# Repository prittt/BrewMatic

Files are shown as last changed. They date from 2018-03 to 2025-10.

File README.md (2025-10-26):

# BrewMatic - Automated Brewing System



<p align="center">
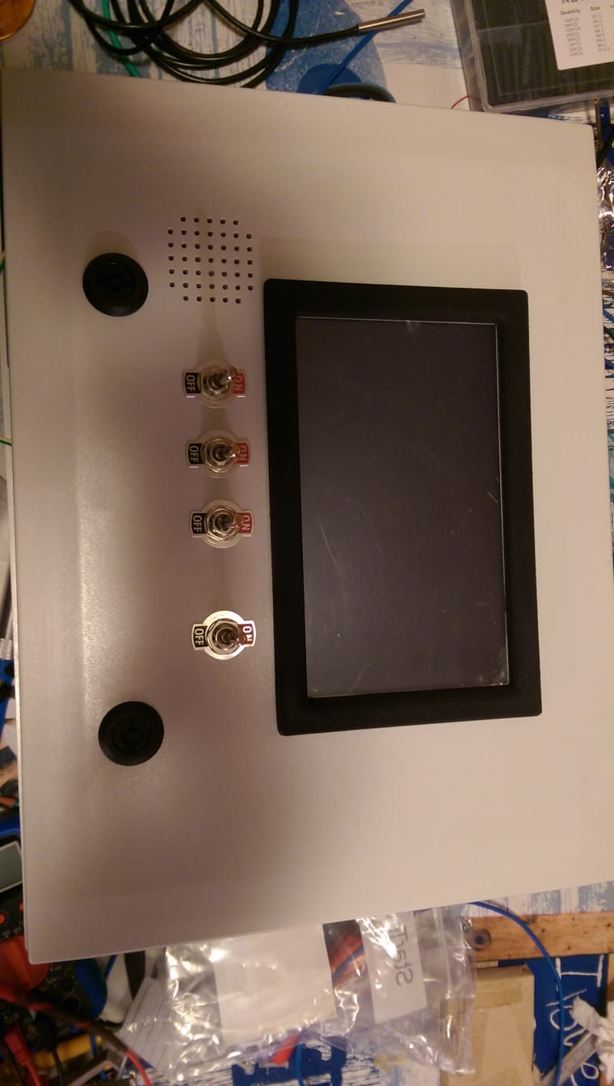
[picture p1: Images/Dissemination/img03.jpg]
  
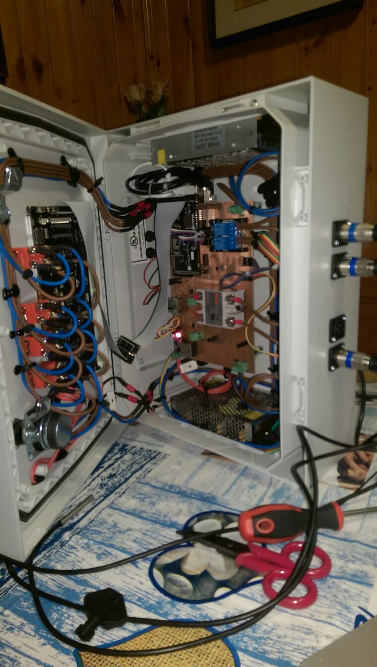
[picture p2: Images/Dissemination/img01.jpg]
  
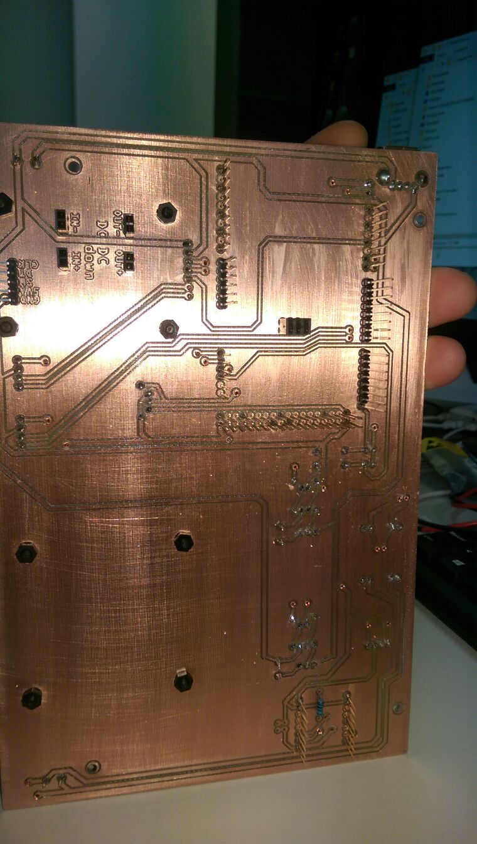
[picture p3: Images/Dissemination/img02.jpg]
  
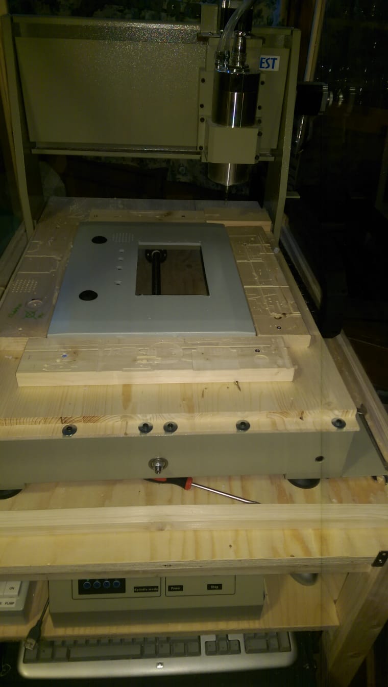
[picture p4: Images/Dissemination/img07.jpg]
  
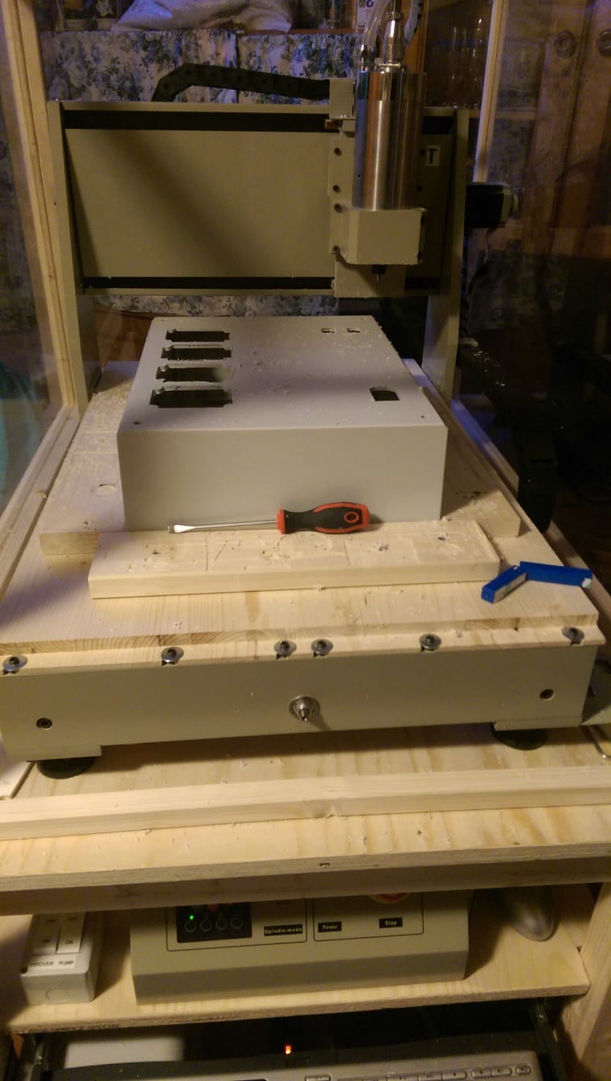
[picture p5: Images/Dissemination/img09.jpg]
  
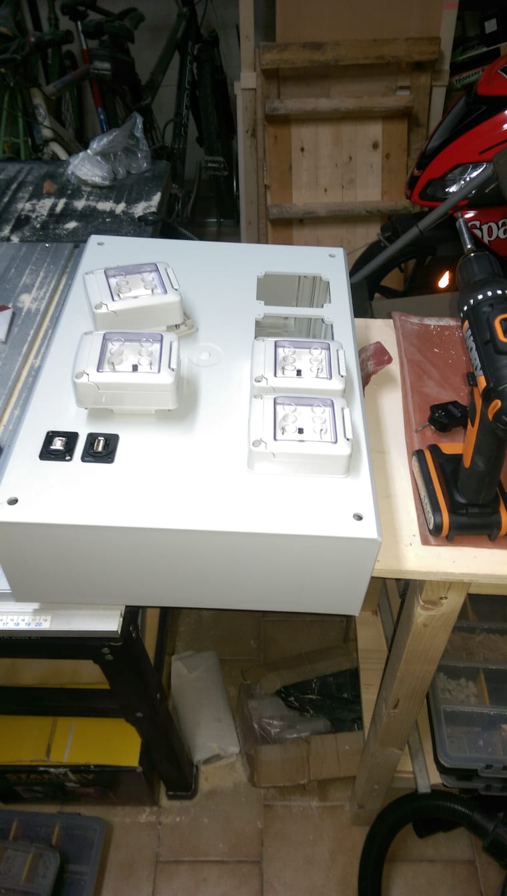
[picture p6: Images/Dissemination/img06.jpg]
  
</p>

<p align="center">
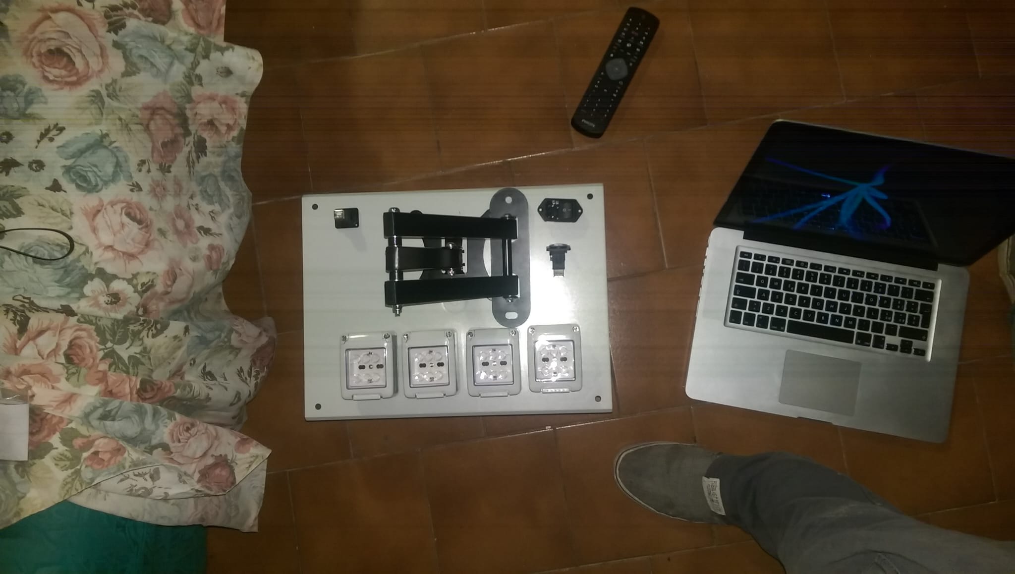
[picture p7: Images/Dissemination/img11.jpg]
  
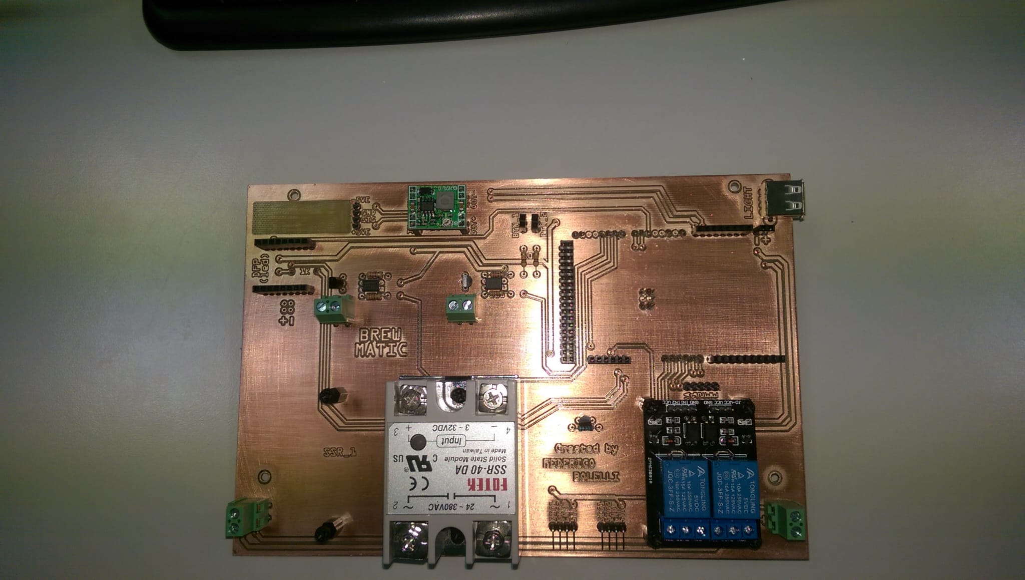
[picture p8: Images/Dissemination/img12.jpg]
  
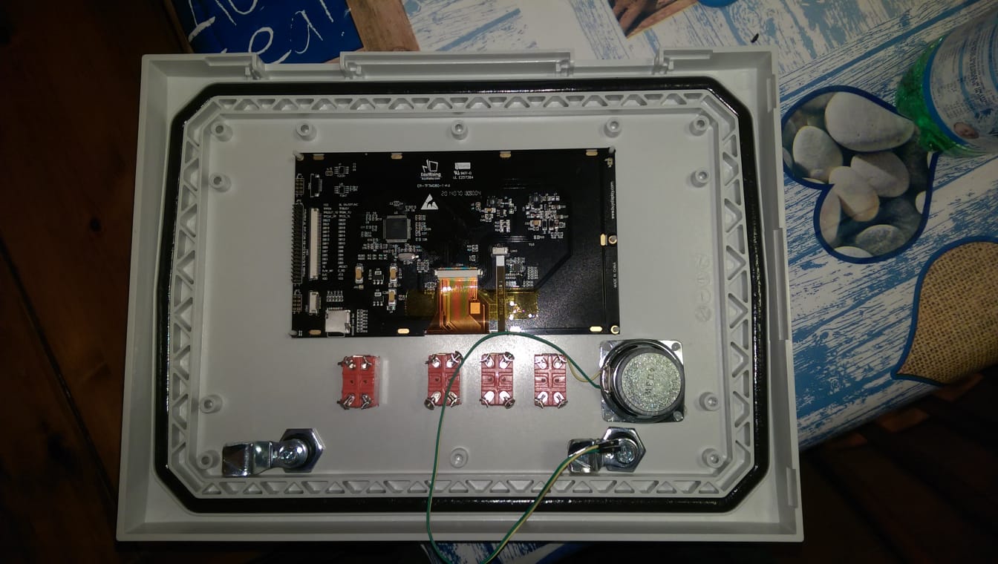
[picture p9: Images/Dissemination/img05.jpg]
  
</p>

An Arduino-based automated brewing control system with touch screen interface for managing mash, sparge, and boil processes.

## Overview

BrewMatic is a comprehensive brewing automation system built on Arduino Mega 2560 with a large TFT touch display (800x480). The system provides automated temperature control, step management, and real-time monitoring for the entire brewing process.

### Key Features

- **Multi-stage Process Control**: Automated management of Mash, Sparge, and Boil phases
- **Temperature Monitoring**: Multiple DS18B20 sensors for precise temperature control
- **Touch Screen Interface**: Intuitive GUI with tabs, buttons, and real-time data visualization
- **Recipe Management**: Configurable brewing recipes with multiple mash steps
- **Safety Features**: Temperature delta monitoring, sensor error detection, hysteresis control
- **Fire Control**: SSR-based heating element control with safety interlocks
- **Audio Feedback**: Buzzer alerts for process transitions

## Hardware Requirements

### Main Components
- **Microcontroller**: Arduino Mega 2560
- **Display**: 800x480 TFT LCD (SSD1963 controller) with resistive touch
- **Temperature Sensors**: DS18B20 (OneWire) sensors for:
  - Mash (upper and lower)
  - Sparge
  - Environment/backup
- **Relays/SSRs**: Solid State Relays for heating element control
- **Audio**: Buzzer for notifications

### Pin Connections
See `mega_pins.h` for detailed pin assignments:
- Temperature sensors on various digital pins
- SSR control pins
- Display connection (38, 39, 40, 41)
- Touch screen interface

## Software Architecture

### Project Versions

The workspace contains three main versions:

1. **BrewMatic**: Original implementation
2. **BrewMaticAlpha01**: First alpha release
3. **BrewMaticAlpha02**: Latest alpha version (recommended)

### Core Libraries Used

- **AWind**: Window/GUI framework for Arduino
- **ASensor**: Sensor management framework
- **AFrame**: Arduino framework for sensor integration
- **UTFT**: TFT display driver
- **UTouch**: Touch screen driver
- **OneWire**: Temperature sensor communication

### Main Components

#### View Layer
- `MenuWindow.h`: Main navigation menu
- `BrewWindow.h`: Tab control for brew processes
- `Mash.h`: Mash process window and controller
- `Sparge.h`: Sparge process window and controller
- `RecipeWindow.h`: Recipe configuration interface
- `SettingsWindow.h`: System settings

#### Controller Layer
- `Recipe.h`: Recipe data structures and configuration
- `PlantParams.h`: Plant-specific parameters
- `utilities.h`: Helper functions and utilities

#### Model Layer
- `SensorManager`: Centralized sensor management
- `DS18B20Sensor`: Temperature sensor wrapper

## Installation

### Library Setup

#### Option 1: Using install_libs.sh (Mac/Linux)

```bash
./install_libs.sh
```

This script creates symbolic links from the project's `libs` folder to your Arduino libraries folder.

#### Option 2: Manual Installation

1. Copy the following libraries to your Arduino libraries folder:
   - `BrewMaticAlpha02/libs/AFrame` → `libraries/BrewMaticAlpha02AFrame`
   - `BrewMaticAlpha02/libs/ASensor` → `libraries/BrewMaticAlpha02ASensor`
   - `BrewMaticAlpha02/libs/AWind` → `libraries/BrewMaticAlpha02AWind`
   - `BrewMaticAlpha02/libs/UTFT` → `libraries/BrewMaticAlpha02UTFT`
   - `BrewMaticAlpha02/libs/UTouch` → `libraries/BrewMaticAlpha02UTouch`

2. Install additional required libraries:
   - OneWire (for DS18B20 sensors)
   - Arduino Timer libraries

### Hardware Setup

1. Connect the TFT display according to UTFT library specifications
2. Wire DS18B20 temperature sensors with 4.7kΩ pull-up resistors
3. Connect SSRs to the designated control pins
4. Wire buzzer for audio feedback
5. Ensure proper power supply for all components

### Configuration

#### Recipe Configuration

Edit `Recipe.h` to configure your brewing recipe:

```cpp
mashStep mashSteps[] = {
    {50, 10, 1, false, 0},  // 50°C for 10 minutes
    {62, 30, 1, false, 0},  // 62°C for 30 minutes
    {72, 20, 1, false, 0},  // 72°C for 20 minutes
    {78, 5,  1, false, 0}   // 78°C for 5 minutes (mash out)
};
```

#### Plant Parameters

Adjust `PlantParams.h` for your specific setup:

```cpp
#define MAX_DELTA 3.0        // Maximum allowed temperature delta
#define HYSTERESIS 0.5       // Temperature control hysteresis
#define INERTIA 2.0          // System thermal inertia
```

## Usage

### Starting a Brew Session

1. **Power On**: The system initializes and displays the main menu
2. **Recipe Selection**: Navigate to the recipe window to select/configure recipe
3. **Sensor Calibration**: Verify all temperature sensors are reading correctly
4. **Start Mash**: 
   - Navigate to Mash tab
   - Press "Start Mash" button
   - Add grains when target mash-in temperature is reached

### Mash Process

The `Mash` class manages multi-step mashing:

- **Temperature Ramp**: Automatically heats to target temperature
- **Rest Period**: Maintains temperature for specified duration
- **Step Progress**: Visual indication of current step and time remaining
- **Iodine Test**: Optional extended rest periods with user control
- **Mash Out**: Final step with buzzer notification

Key features:
- Real-time temperature display (upper, lower, average)
- Fire status indicator
- Step progress visualization
- Manual step duration adjustment

### Sparge Process

The `Sparge` class manages sparge water heating:

- Target temperature: 78°C (configurable)
- Automatic fire control
- Temperature monitoring
- Completion notification

### Safety Features

1. **Temperature Delta Check**: 
   - Monitors difference between upper and lower mash sensors
   - Automatically disables heating if delta exceeds threshold
   - Prevents scorching and uneven heating

2. **Sensor Error Detection**:
   - Validates sensor readings
   - Disables heating on sensor failures
   - Visual and audio warnings

3. **Hysteresis Control**:
   - Prevents rapid on/off cycling
   - Extends equipment lifespan

## Development

### Project Structure

```
BrewMaticAlpha02/
├── BrewMaticAlpha02.ino    # Main Arduino sketch
├── libs/                    # Core libraries
│   ├── AFrame/             # Arduino framework
│   ├── ASensor/            # Sensor management
│   ├── AWind/              # GUI framework
│   ├── UTFT/               # Display driver
│   └── UTouch/             # Touch driver
├── Mash.h                  # Mash process (View + Controller)
├── Sparge.h                # Sparge process
├── MenuWindow.h            # Main menu
├── BrewWindow.h            # Tab control
├── Recipe.h                # Recipe configuration
├── PlantParams.h           # System parameters
└── utilities.h             # Helper functions
```

### Key Classes

#### Mash Class
Location: `Mash.h`

Implements both View and Controller for the mash process:

```cpp
class Mash : public Window, 
             public ISensorHasDataEventReceiver, 
             public ISensorMeasuredEventReceiver, 
             public ITouchEventReceiver
{
    // View components
    TextBoxString *mash_up_temp_str_;
    TextBoxString *mash_down_temp_str_;
    TextBoxString *mash_avg_temp_str_;
    ImageWindow *flames_img_;
    
    // Controller methods
    void HandleStep();
    void CheckTemperatures();
    void SetFire();
    void UpdateScreenStepData();
};
```

#### SensorManager
Location: `libs/AFrame/SensorManager.h`

Manages sensor measurements and event notifications:

```cpp
SensorManager *mash_up_temp_manager = new SensorManager(
    mash_up_temp, -10, 110, 1000*10, false, F("MASH_UP")
);
```

### Adding New Features

1. **New Sensor**: Create sensor in `setup()`, register with `SensorManager`
2. **New Window**: Inherit from `Window`, implement `ISensorHasDataEventReceiver`
3. **New Recipe Step**: Modify `mashStep` structure in `Recipe.h`

## Examples

The `Arduino Project Examples` folder contains isolated examples:

- **all_together**: Combined hardware test
- **buttons**: Button handling examples
- **Music_Player**: DFPlayer integration
- **TemperatureSensor**: DS18B20 sensor examples
- **ScreenDrawingTest**: Display graphics tests
- **SD_on_LCD_screen**: SD card bitmap display

## Hardware Enclosure

The `Case` folder contains:
- Front panel design
- Back panel design
- Frame specifications
- CNC machining instructions

## PCB Designs

The `PCBs` folder contains circuit board designs for:
- Temperature sensor connections
- Power distribution
- Control interfaces

## License

This project uses multiple open-source libraries with different licenses:

- **AWind Library**: Apache License 2.0
- **BrewMatic Code**: BSD 3-Clause License (see file headers)
- **UTFT Library**: CC BY-NC-SA 3.0

Copyright (c) 2018 Federico Bolelli

## Contributing

When contributing to this project:

1. Follow the existing code style
2. Test thoroughly with actual hardware
3. Update documentation for new features
4. Add examples for complex functionality

## Troubleshooting

### Display Issues
- Verify pin connections match `BrewMaticAlpha02.ino` setup
- Check backlight pin (pin 8) is HIGH
- Ensure UTFT library is correctly installed

### Sensor Problems
- Verify 4.7kΩ pull-up resistor on OneWire bus
- Check sensor addresses using OneWire scanner
- Monitor Serial output for sensor readings

### Touch Not Responding
- Run touch calibration
- Update calibration values in `UTouchCD.h`
- Check precision setting: `myTouch.setPrecision(PREC_MEDIUM)`

### Memory Issues
- Arduino Mega has limited SRAM
- Use `F()` macro for string literals
- Monitor free RAM: `AHelper::LogFreeRam()`

## Useful Links

- Link Utili PID-SSR: See `Link Utili PID-SSR.txt`
- Link Utili Speaker: See `Link Utili Speaker.txt`

---

**Note**: This is an active development project. Always refer to the latest code in `BrewMaticAlpha02` for the most current implementation.

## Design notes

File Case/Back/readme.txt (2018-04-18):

single height step: 2mm candle cutter
time: few minutes
vertical zero: upper surface - plastic thickness

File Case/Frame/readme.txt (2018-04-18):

roughing: 3mm spherical cutter
finishing: 3mm spherical cutter
time: more than 4 hours
material: wooden
material thickness: 6mm
vertical zero: lower face of the material

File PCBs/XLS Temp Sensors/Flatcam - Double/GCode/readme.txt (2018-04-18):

traces: 0.5mm candle or better V-cutter like http://pcbfacile.com/frese-v-groove-a-spirale/151--fresa-per-scoring-30-in-carburo-di-tungsteno-flat-version-802.html
holes: 0.8mm candle cutter (better if it is for alluminium like http://pcbfacile.com/frese-per-alluminio/2387-frese-2-taglienti-in-carburo-solido-per-alluminio-08mm-.html)
board cutout: 3mm candle cutter
time: few minutes
vertical zero: PCB upper surface

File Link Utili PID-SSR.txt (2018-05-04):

PID: 

Arduino Library:
https://playground.arduino.cc/Code/PIDLibraryConstructor

Additional Theoretical Information
http://brettbeauregard.com/blog/2017/06/introducing-proportional-on-measurement/

Forums (Similar Issue): 
http://forum.arduino.cc/index.php?topic=5678.0
http://forum.arduino.cc/index.php?topic=155720.0

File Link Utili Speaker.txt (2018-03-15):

https://www.arduino.cc/en/Tutorial/SimpleAudioPlayer

https://maker.pro/projects/arduino/arduino-audio-player

Robot Italy
product: https://www.robot-italy.com/it/dfplayer-a-mini-mp3-player-for-arduino.html
links:  
	https://www.dfrobot.com/wiki/index.php/DFPlayer_Mini_SKU:DFR0299

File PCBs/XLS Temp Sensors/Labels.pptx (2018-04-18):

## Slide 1

XLS labels

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
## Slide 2

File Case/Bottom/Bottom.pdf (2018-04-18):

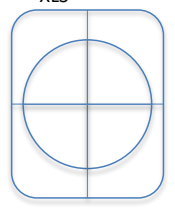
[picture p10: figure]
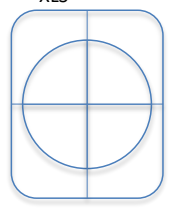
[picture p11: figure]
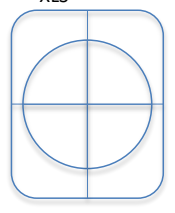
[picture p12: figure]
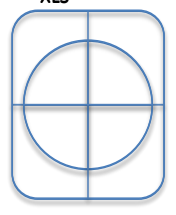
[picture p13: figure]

XLS | XLS | XLS | XLS

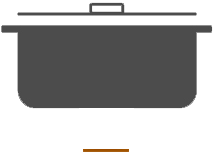
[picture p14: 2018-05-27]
Images/TunNoFire.png

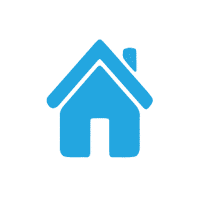
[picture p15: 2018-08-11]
Images/ImmaginiOriginali/home.png

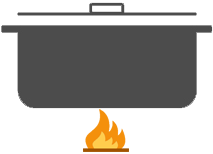
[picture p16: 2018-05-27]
Images/TunFire.png

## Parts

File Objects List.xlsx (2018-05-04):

Legend
 | Different Seller
 |  | Actual Price |  |  |  | Alternative Price
 | Description | Object [€] | Delivery [€] | Shop | Link | Object [€] | Delivery [€] | Shop | Link
 | Lcd Screen 8'' | 47.70175439 | 9.561403509 | BuyLcd | https://www.buydisplay.com/default/8-inch-arduino-touch-screen-shield-ssd1963-library-for-mega-due
 | Touch Panel 8'' | 6.754385965
 | Arduino Mega 2560 R3 | 10.70175439
 | Arduino Relé Module (Optocoupled!) | 1 | 2.2 | Ebay | https://www.ebay.it/itm/Modulo-Scheda-Rele-2-Canali-Optoisolati-10A-250V-per-Arduino-Shield-5Vdc-Con-Led/182567022479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
 | SSR Module | 4.95 | 2.95 | Ebay | http://www.ebay.it/itm/Rel%C3%A8-SSR-40DA-statico-stato-solido-40A-380-24Vac-32-3Vdc-solid-state-relay/322373636211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
 | Power Supply 12V - 10A | 8.99 | 0 | Ebay | https://www.ebay.it/itm/AC-DC220V-A-DC-5-12-24-48V-Fuente-ALIMENTATORE-Driver-LED-12W-720W-TRASFORMATORE/382121409981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
 | Power Supply 5V - 10A | 11.99
 | Cabled DS18B20 Sensor (x5) | 10 | 6.5 | Ebay | https://www.ebay.it/itm/SONDA-DS18B20-SENSORE-DI-TEMPERATURA-da-55-a-125-C-ARDUINO-ART-CD06/261141793540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
 | DS18B20 Sensor | 1.038 | 0 | Ebay | https://www.ebay.it/itm/5PCS-DS18B20-18B20-TO-92-1-Wire-Digital-Thermometer-Temperature-Sensor-TE242/401516576346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
 | Arduino Mega Stackable Header Pin | 3.49 | 0.9 | Ebay | https://www.ebay.it/itm/Arduino-MEGA-Stackable-Female-Header-Pin-Shield-Kit-5x8-1x10-1x-2x3-1x-2x18/121492749450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
 | LM386 Amplifier | 3.1 | 3.99 | Ebay | https://www.ebay.it/itm/LM386-Audioverst%C3%A4rker-Module-Audio-Verst%C3%A4rker-Amplifier-Module-Arduino-Raspberry/162384191843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
 | Switch 220V - 15A (x4) | 3.96 | 0 | AliExpress | https://it.aliexpress.com/item/Toggle-switch-Shake-head-rocker-switch-E-TEN1221-4-feet-2-15-a-250-v/32819810232.html
 | Arduino Power Cable Adapter | 0.42 | 0 | AliExpress | https://it.aliexpress.com/item/Free-shipping-10Pair-10pcs-female-10pcs-male-Male-Female-5-5-x-2-1mm-DC-Power/32663468409.html
 | Electric Terminal | 0.648 | 0 | AliExpress | https://it.aliexpress.com/item/10Pcs-Lot-KF129-2Pin-5-08mm-pitch-Terminal-Connectors-PCB-terminal-2P-300V-25A/32803344826.html
?? | Momentary Button (x2) | 1.494 | 0 | Ebay | --------
 | Male XLS Connector (x4) | 6 | 0 | AliExpress | https://it.aliexpress.com/item/2PCS-YT134-Gold-plated-cannon-plug-Microphone-connector-3-core-Cannon-balance-plugs-Free-Shipping/32723748205.html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
 | Female PCB XLS (x4) | 2.88 | 0 | Amazon | https://www.amazon.it/gp/product/B016XVMSO0/ref=oh_aui_detailpage_o05_s00?ie=UTF8&psc=1
 | DFPlayer | 3.098 | 0 | Amazon | https://www.amazon.it/gp/product/B07912P1XL/ref=oh_aui_detailpage_o02_s00?ie=UTF8&psc=1
 | Speaker | 5.605 | 0 | Amazon | https://www.amazon.it/gp/product/B073XH8KK8/ref=oh_aui_detailpage_o03_s00?ie=UTF8&psc=1
 | Power Cable | 0.745 | 0 | Ebay | https://www.ebay.it/itm/20-Cavi-di-Alimentazione-Schuko-IEC-60320-C13-1-5Mt-Nuovi/163005547466
 | Panel Plug + Switch | 2.78 | 0 | AliExpress | https://it.aliexpress.com/item/Double-way-AC-power-Switch-10A-250V-ac-3-Terminal-Power-Socket/32719529113.html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
 | PCB Electrical Resistances | 9.98 | 0 | Amazon | https://www.amazon.it/gp/product/B00J02WSFE/ref=oh_aui_detailpage_o08_s00?ie=UTF8&psc=1 | 5.46 | 0 | AliExpress | https://it.aliexpress.com/item/Best-Promotion-1000-Pcs-50-Values-1-4W-Metal-Film-Resistors-Resistance-Assortment-Kit-Set-1/32662610149.html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
 | DC-DC Step Down Adapter | 1.998 | 0 | Amazon | https://www.amazon.it/gp/product/B01MQGMOKI/ref=oh_aui_detailpage_o08_s00?ie=UTF8&psc=1
 | PCB Double Face Copper (300x210) | 6.43 | 7.5 | PCB Facile | http://pcbfacile.com/
 | PCB Single Face Copper (100x70) | 2.2
 | Aluminum Cutter 0.8mm | 11.53
 | V Cutter (Flat) 30° | 12.04
 | Single-Cutting Blade (acrylic) | 19.22
 | Ball Cutter 3mm | 18.06
 | 2.54mm PIN Strip (x2) | 2.92
 | USB PCB Female A 90° | 0.6
 | USB Cable A-90°B | 3.99 | 0 | Amazon | https://www.amazon.it/gp/product/B00GURMTTC/ref=oh_aui_detailpage_o04_s00?ie=UTF8&th=1
 | USB Cable A-B | 1.53 | 6 | RS | https://it.rs-online.com/web/ma/myaccount/tuoidettagliordine/?refNumber=142036944
 | USB Panel FemaleA-FemaleB | 9.53
 | Cable 3 cond 4.8mm (x12) | 12.7416
 | Sharp PC817X2NSZ0F Photocoupler | 0.148
 | USB Panel FemaleB-FemaleA | 7.05
 | Jumpers 40 cm | 0.658 | 0 | Amazon | https://www.amazon.it/s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
 | Jumpers 20 cm | 1.196 | 0 | Amazon | https://www.amazon.it/gp/product/B00RCYIPV8/ref=oh_aui_search_detailpage?ie=UTF8&th=1
 | Jumpers 10 cm | 1.46 | 0 | AliExpress | https://it.aliexpress.com/item/Dupont-line-120pcs-10cm-male-to-male-male-to-female-and-female-to-female-jumper-wire/32352232311.html
 | Plastic Screws | 4.5 | 0 | Amazon | https://www.amazon.it/gp/product/B01FQSL1DK/ref=oh_aui_detailpage_o09_s00?ie=UTF8&psc=1
 | Metal Screws (2.9x13 + 3.5x9.5 + 5.5x_) | 0.9646 | 0 | Obi | --------
 | Washers (_x_) | 0.596 | 0 | Obi | --------
 | Copper Wire (x20) | 3.38 | 0 | Bricoman | -------- | --------
 | Crimp Terminal | 4.5 | 0 | BricoMan | --------
 | Heat-Shrink Sheath | 2.4975 | 0 | Amazon | https://www.amazon.it/gp/product/B076KL5K1V/ref=oh_aui_detailpage_o01_s00?ie=UTF8&psc=1
 | 20x2 FlatCable | 2.9 | 4.9 | Futura Elettronica | https://www.futurashop.it/cavo-flat-con-2-connettori-ff-2x20-pin-2846-pod40?search=2x20
 | Case | 67.22 | 0 | Automation24 | https://www.automation24.it/armadio-a-parete-fibox-arca-403015-8120006
?? | Schuko Plug Gewiss (x4) | 18.8 | 0 | BricoMan | --------
?? | Panel Plug Case (x4) | 11 | 0 | BricoMan | --------
 | 2.54mm 2PIN Female Header | 0.18125 | 0 | AliExpress | https://it.aliexpress.com/item/200PCS-2Pin-2-54mm-Single-Row-Straight-Female-Pin-Header-2P-Strip-PBC/32769053076.html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
 | 2.54mm 8PIN Female Header | 0.098 | 0 | AliExpress | https://it.aliexpress.com/item/10PCS-1x8-Single-Row-8-Pins-PCB-Socket-Female-Header-2-54mm-8-Pin-8Pin-3mm/32863954320.html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
 | Spray Can Black | 4.99 | 0 | Obi | --------
 | Wooden Plait (2x4mm + 1x10mm) | 15 | 0 | Obi | --------
 | Wooden Screw 25mm | 15.6 | 0 | Obi | --------
 | SD Card 128 MB (x2) | 4.4 | 0 | AliExpress | https://it.aliexpress.com/item/AMZDEAL-Ad-Alta-Velocit-Micro-SD-Card-Scheda-di-Memoria-128-MB-512-MB-1-GB/32850679274.html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
?? | Electrolitic Capacitor | 0.4 | 0 | Ebay
?? | Tantalum Capacitor | 0.10 | 0 | Ebay
 | TV support | 14.99 | 0 | Amazon | https://www.amazon.it/gp/product/B00E89QN3C/ref=oh_aui_detailpage_o04_s00?ie=UTF8&psc=1
 |  | 432.7448447 | 44.50140351 | -------> | 477.2462482 | 5.46 | 0 | -------> | 5.46

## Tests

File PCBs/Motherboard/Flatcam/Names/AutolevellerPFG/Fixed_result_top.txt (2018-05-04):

X0.0604 Y0.038 Z-1.0E-4
X0.45 Y0.038 Z0.00177
X0.8396 Y0.038 Z0.00325
X1.2292 Y0.038 Z0.00443
X1.6188 Y0.038 Z0.006
X2.0084 Y0.038 Z0.00728
X2.398 Y0.038 Z0.00906
X2.7876 Y0.038 Z0.01024
X3.1772 Y0.038 Z0.01152
X3.5668 Y0.038 Z0.0125
X3.9564 Y0.038 Z0.01319
X4.346 Y0.038 Z0.01378
X4.7356 Y0.038 Z0.01388
X5.1252 Y0.038 Z0.01368
X5.5148 Y0.038 Z0.01348
X5.9044 Y0.038 Z0.01289
X6.294 Y0.038 Z0.0122
X6.6836 Y0.038 Z0.01132
X7.0732 Y0.038 Z0.01024
X7.4628 Y0.038 Z0.00876
X7.8524 Y0.038 Z0.00709
X8.242 Y0.038 Z0.00541
X8.242 Y0.42561 Z0.00689
X7.8524 Y0.42561 Z0.00856
X7.4628 Y0.42561 Z0.01004
X7.0732 Y0.42561 Z0.01142
X6.6836 Y0.42561 Z0.0125
X6.294 Y0.42561 Z0.01348
X5.9044 Y0.42561 Z0.01417
X5.5148 Y0.42561 Z0.01457
X5.1252 Y0.42561 Z0.01467
X4.7356 Y0.42561 Z0.01467
X4.346 Y0.42561 Z0.01457
X3.9564 Y0.42561 Z0.01407
X3.5668 Y0.42561 Z0.01329
X3.1772 Y0.42561 Z0.0125
X2.7876 Y0.42561 Z0.01122
X2.398 Y0.42561 Z0.00984
X2.0084 Y0.42561 Z0.00827
X1.6188 Y0.42561 Z0.00699
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

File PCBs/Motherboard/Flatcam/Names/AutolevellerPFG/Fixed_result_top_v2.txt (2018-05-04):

X0.0604 Y0.038 Z1.0E-4
X0.45 Y0.038 Z0.00177
X0.8396 Y0.038 Z0.00325
X1.2292 Y0.038 Z0.00472
X1.6188 Y0.038 Z0.0062
X2.0084 Y0.038 Z0.00738
X2.398 Y0.038 Z0.00896
X2.7876 Y0.038 Z0.01024
X3.1772 Y0.038 Z0.01152
X3.5668 Y0.038 Z0.0126
X3.9564 Y0.038 Z0.01339
X4.346 Y0.038 Z0.01378
X4.7356 Y0.038 Z0.01398
X5.1252 Y0.038 Z0.01378
X5.5148 Y0.038 Z0.01358
X5.9044 Y0.038 Z0.01289
X6.294 Y0.038 Z0.01211
X6.6836 Y0.038 Z0.01132
X7.0732 Y0.038 Z0.01014
X7.4628 Y0.038 Z0.00876
X7.8524 Y0.038 Z0.00728
X8.242 Y0.038 Z0.00561
X8.242 Y0.42561 Z0.00709
X7.8524 Y0.42561 Z0.00876
X7.4628 Y0.42561 Z0.01033
X7.0732 Y0.42561 Z0.01161
X6.6836 Y0.42561 Z0.0127
X6.294 Y0.42561 Z0.01358
X5.9044 Y0.42561 Z0.01417
X5.5148 Y0.42561 Z0.01467
X5.1252 Y0.42561 Z0.01486
X4.7356 Y0.42561 Z0.01496
X4.346 Y0.42561 Z0.01457
X3.9564 Y0.42561 Z0.01407
X3.5668 Y0.42561 Z0.01339
X3.1772 Y0.42561 Z0.0125
X2.7876 Y0.42561 Z0.01112
X2.398 Y0.42561 Z0.00974
X2.0084 Y0.42561 Z0.00856
X1.6188 Y0.42561 Z0.00699
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

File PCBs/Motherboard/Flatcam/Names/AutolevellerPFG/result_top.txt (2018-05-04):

0.06029,0.03789,-0.00010 
0.44980,0.03789,0.00177 
0.83957,0.03789,0.00325 
1.22908,0.03789,0.00443 
1.61860,0.03789,0.00600 
2.00837,0.03789,0.00728 
2.39788,0.03789,0.00906 
2.78740,0.03802,0.01024 
3.17717,0.03802,0.01152 
3.56668,0.03789,0.01250 
3.95620,0.03789,0.01319 
4.34596,0.03789,0.01378 
4.73548,0.03789,0.01388 
5.12500,0.03789,0.01368 
5.51476,0.03789,0.01348 
5.90428,0.03789,0.01289 
6.29380,0.03789,0.01220 
6.68356,0.03789,0.01132 
7.07308,0.03789,0.01024 
7.46260,0.03789,0.00876 
7.85236,0.03789,0.00709 
8.24188,0.03789,0.00541 
8.24200,0.42557,0.00689 
7.85236,0.42557,0.00856 
7.46284,0.42557,0.01004 
7.07320,0.42557,0.01142 
6.68381,0.42544,0.01250 
6.29405,0.42544,0.01348 
5.90453,0.42544,0.01417 
5.51501,0.42557,0.01457 
5.12525,0.42544,0.01467 
4.73573,0.42544,0.01467 
4.34621,0.42544,0.01457 
3.95645,0.42544,0.01407 
3.56693,0.42544,0.01329 
3.17741,0.42544,0.01250 
2.78765,0.42557,0.01122 
2.39813,0.42544,0.00984 
2.00861,0.42557,0.00827 
1.61885,0.42557,0.00699 
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

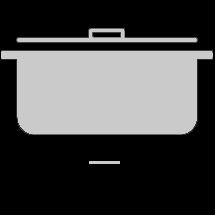
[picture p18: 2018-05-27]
Arduino Project Examples/ScreenDrawingTest/tun.bmp

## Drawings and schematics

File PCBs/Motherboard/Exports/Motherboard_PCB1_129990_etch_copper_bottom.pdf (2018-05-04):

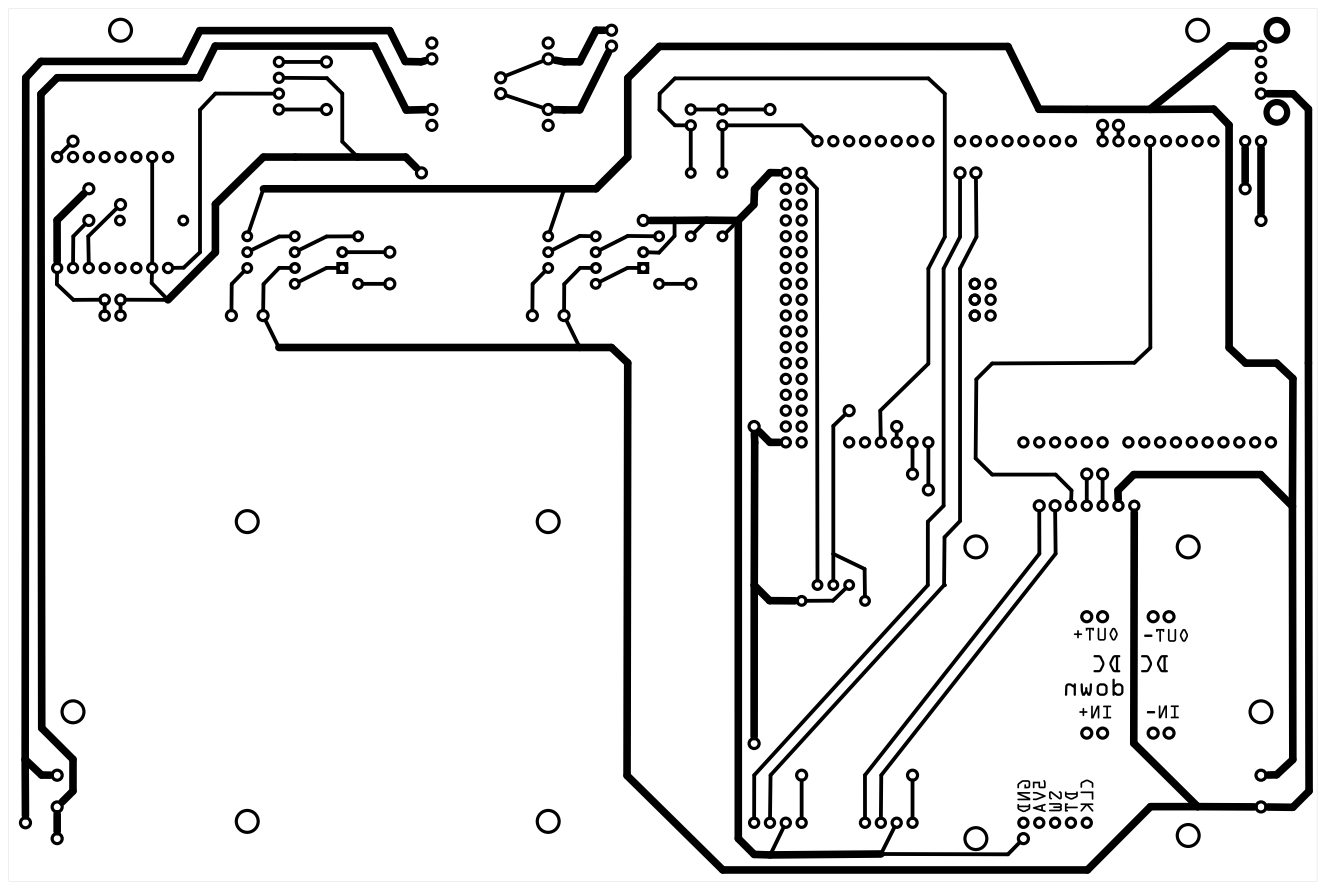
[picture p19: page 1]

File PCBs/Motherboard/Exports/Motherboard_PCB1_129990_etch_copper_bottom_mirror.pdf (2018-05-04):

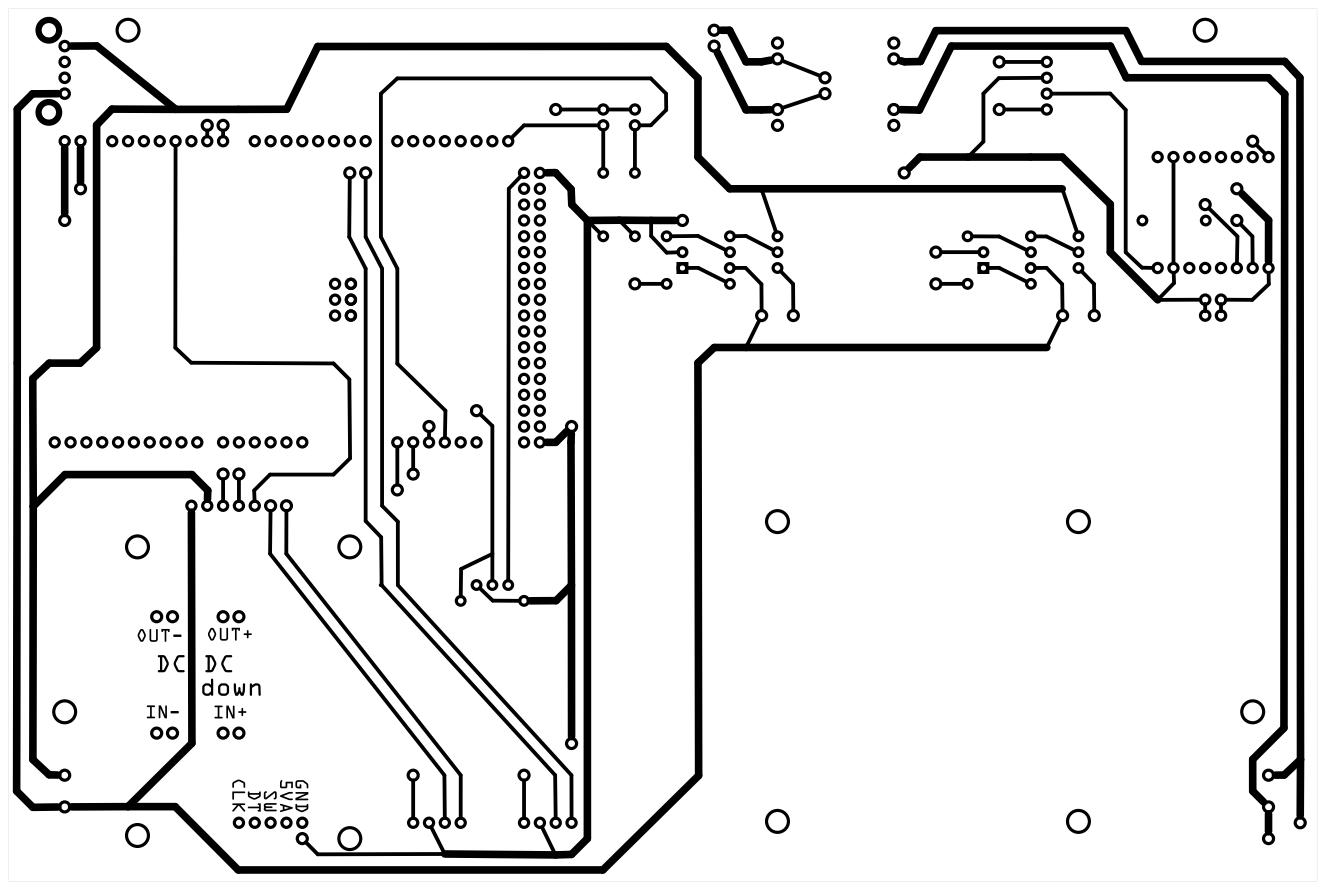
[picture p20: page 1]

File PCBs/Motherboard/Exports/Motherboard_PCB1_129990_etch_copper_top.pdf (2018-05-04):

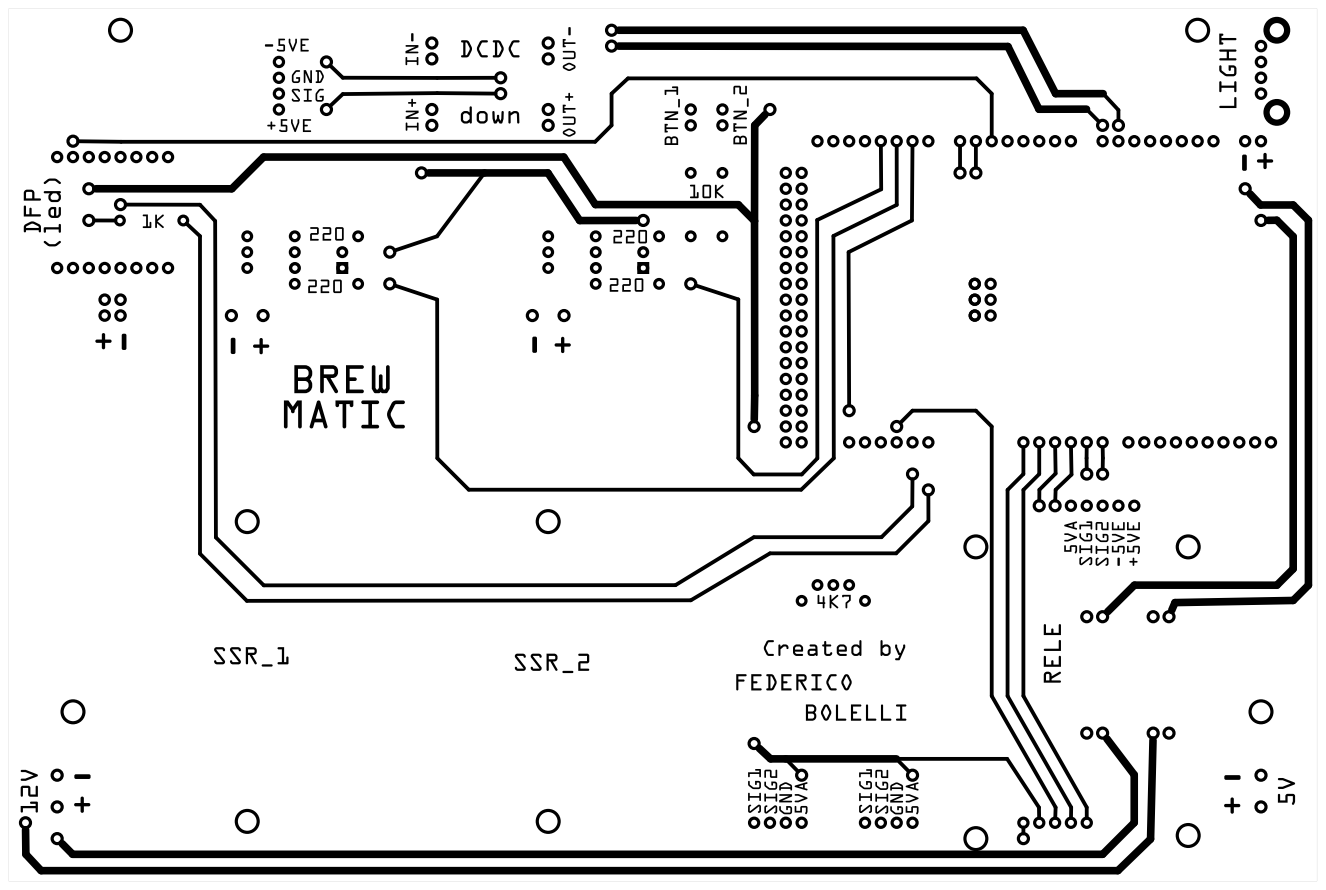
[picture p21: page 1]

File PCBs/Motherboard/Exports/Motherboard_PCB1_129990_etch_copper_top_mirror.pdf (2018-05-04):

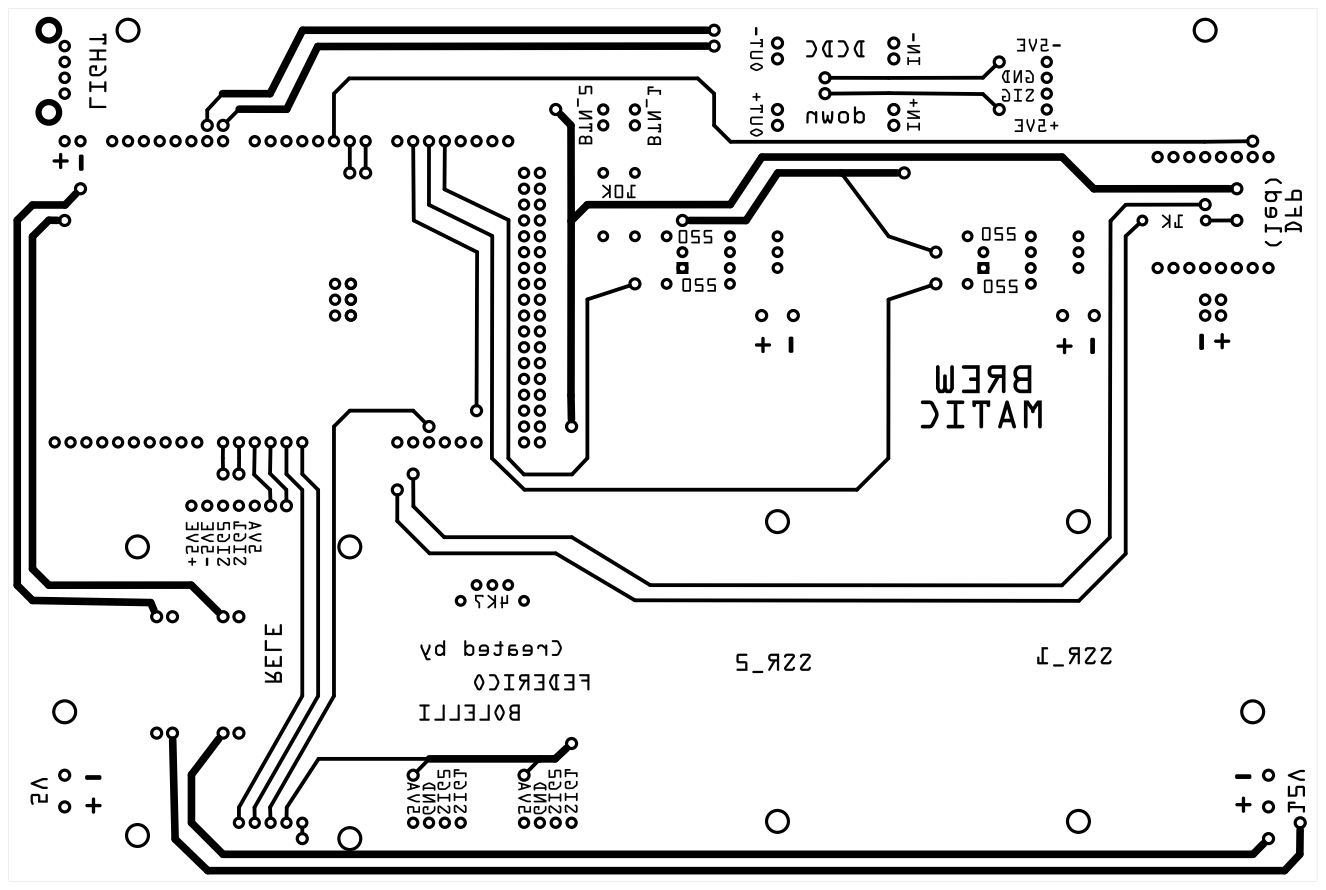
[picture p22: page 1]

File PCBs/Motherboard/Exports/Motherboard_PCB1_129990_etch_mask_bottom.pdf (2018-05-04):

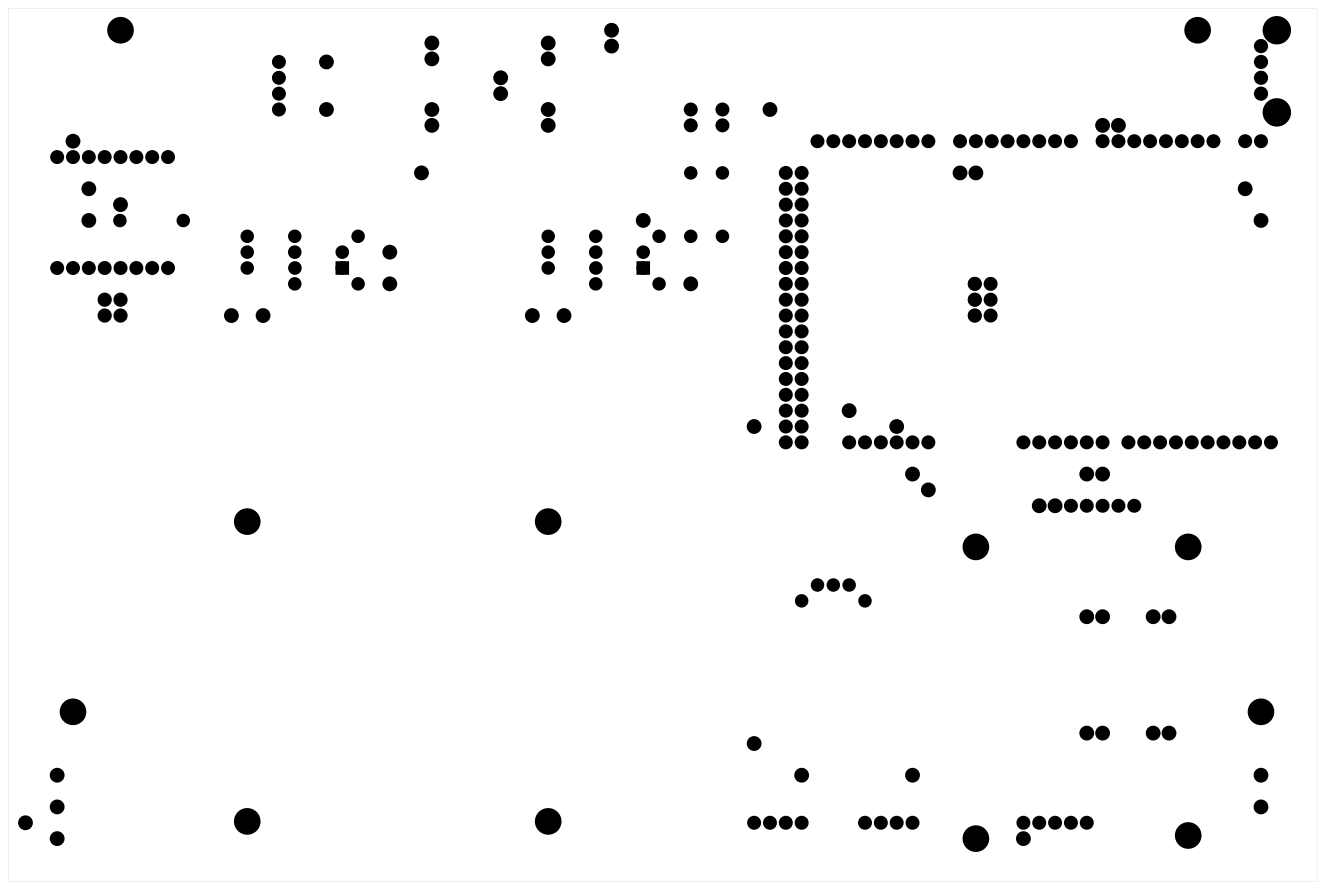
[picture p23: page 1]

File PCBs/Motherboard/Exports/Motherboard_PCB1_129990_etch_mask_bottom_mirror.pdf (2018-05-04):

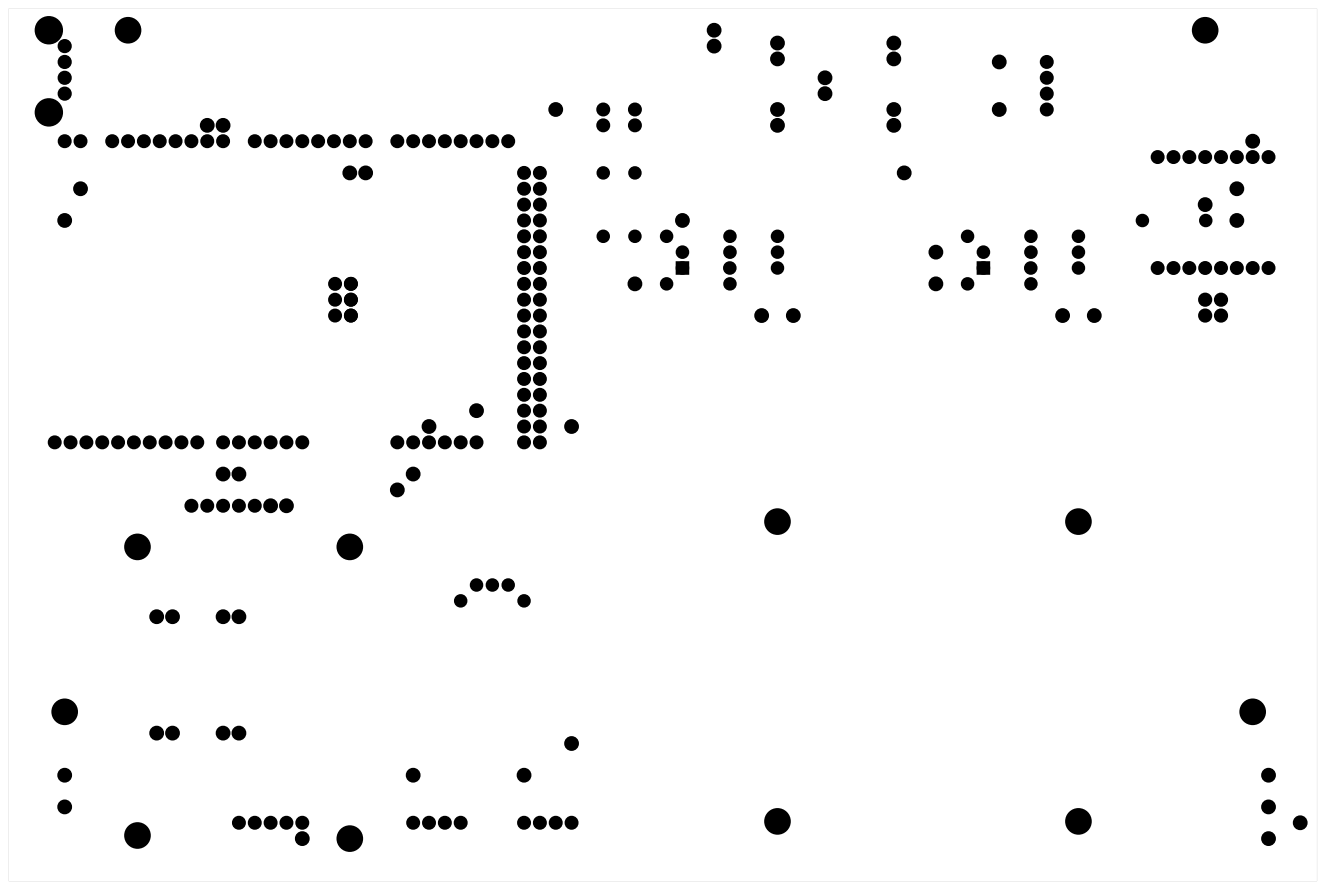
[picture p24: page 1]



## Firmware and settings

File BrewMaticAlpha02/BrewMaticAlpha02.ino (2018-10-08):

// Copyright(c) 2018 Federico Bolelli
//
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
// * Neither the name of BrewMatic nor the names of its
// contributors may be used to endorse or promote products derived from
// this software without specific prior written permission.
//
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
#include "Log.h"

#include "DC_UTFT.h"
#include "TouchUTFT.h"

#include "LinkedList.h"
#include "WindowsManager.h"
#include "DefaultDecorators.h"


#include "SettingsWindow.h"
#include "RecipeWindow.h"
#include "BrewWindow.h"

#include "OneWire.h"

#include "SensorManager.h"
#include "DS18B20Sensor.h"
#include "MeasurementNode.h"

#include "MenuWindow.h"

#include "ImageButton.h"

#include "mega_pins.h"

#include "Mash.h"
#include "Sparge.h"
#include "Boil.h"

extern Image brew60x60;
extern Image settings60x60;
extern Image recipe60x60;

// CONTROLLER
#include "Recipe.h"

UTFT myGLCD(SSD1963_800480,38,39,40,41);  //(byte model, int RS, int WR, int CS, int RST, int SER)
UTouch  myTouch(43, 42, 44, 45, 46);  //byte tclk, byte tcs, byte din, byte dout, byte irq

DC_UTFT dc(&myGLCD);
TouchUTFT touch(&myTouch);

// Manager which is responsible for window updating process
WindowsManager<MenuWindow> windowsManager(&dc,&touch);

// List in which all sensors are collected
LinkedList<SensorManager> sensors;
MeasurementNode measurementNode(sensors,NULL);

// Mash window + controller
Mash *mash;

// Sparge window + controller
Sparge *sparge;

void InitMenuButtonDecorator(){
  DecoratorList *list = new DecoratorList();
  list->Add(new DecoratorRectFill(Color::SteelBlue, true));
  //list->Add(new DecoratorRoundRect(tSteelBlue));
  Environment::Get()->RegisterDecoratorsGroup(F("MenuButton"), list);
}

void InitSensorDecorator(){
  DecoratorList *list = new DecoratorList();
  list->Add(new DecoratorRectFill(Color::Black, false));
  list->Add(new DecoratorColor(Color::White));
  Environment::Get()->RegisterDecoratorsGroup(F("Sensor"), list);
}

void InitBrewTabCurrentButtonsDecorator(){
  DecoratorList *list = new DecoratorList();
  list->Add(new DecoratorChromeTabBox(true));
  list->Add(new DecoratorColor(Color::Black));
  //list->Add(new DecoratorRoundRect(Color::White));
  Environment::Get()->RegisterDecoratorsGroup(F("BrewCurTab"), list);
}

void InitBrewTabOtherButtonsDecorator(){
  DecoratorList *list = new DecoratorList();
  list->Add(new DecoratorChromeTabBox(false));
  list->Add(new DecoratorColor(Color::White));
  //list->Add(new DecoratorRoundRect(Color::White));
  Environment::Get()->RegisterDecoratorsGroup(F("BrewOtherTab"), list);
}

void InitBrewWindowDecorator(){
  DecoratorList *list = new DecoratorList();
  list->Add(new DecoratorRectFill(Color::Black, false));
  list->Add(new DecoratorColor(Color::White));
  Environment::Get()->RegisterDecoratorsGroup(F("BrewWindow"), list);
}

void setup()
{

	// Setup log (out is wrap about Serial class)
	out.begin(9600);
	out<<F("Setup")<<endln;

	// Initialize display
	myGLCD.InitLCD(); 
	myGLCD.clrScr();

  // -------------------------------------------------------------
  pinMode(8, OUTPUT);    //backlight 
  digitalWrite(8, HIGH); //on
  // -------------------------------------------------------------

	// Initialize touch
	myTouch.InitTouch();
	myTouch.setPrecision(PREC_MEDIUM);

	DC_UTFT::RegisterDefaultFonts();
  
	// Initialize apperance. Create your own DefaultDecorators class if you would like different application look
  InitSensorDecorator();
  InitMenuButtonDecorator();

  InitBrewTabCurrentButtonsDecorator();
  InitBrewTabOtherButtonsDecorator();
  
  
	DefaultDecorators::InitAll();
  
	// Initialize window manager
	windowsManager.Initialize();

  RecipeWindow *win_recipe = new RecipeWindow(F("Recipe"),0,0,200,200);
  SettingsWindow *win_settings = new SettingsWindow(F("Settings"),0,0,200,2000);
  BrewWindow *brew_win = new BrewWindow(F("TabControl"), 50, 40, 700, 380);

  mash = new Mash(F("Mash"), 5, 25, 690, 350); // (+5 pixel top e left - 10 widt, - 30 heigh, perchè diventeranno i figli di brew_win) Parametri collegati alle dimensioni dei tab nella brew_win -> TODO trasformarein variabili 
  sparge = new Sparge(F("Sparge"), 5, 25, 690, 350); // (+5 pixel top e left - 10 widt, - 30 heigh, perchè diventeranno i figli di brew_win) Parametri collegati alle dimensioni dei tab nella brew_win -> TODO trasformarein variabili
  Boil *boil = new Boil(F("Boil"), 5, 25, 690, 350);  // (+5 pixel top e left - 10 widt, - 30 heigh, perchè diventeranno i figli di brew_win) Parametri collegati alle dimensioni dei tab nella brew_win -> TODO trasformarein variabili
  brew_win->AddTab(F("Mash"), mash); 
  brew_win->AddTab(F("Sparge"),sparge);
  brew_win->AddTab(F("Boil"), boil);

  // Menu buttons
	windowsManager.MainWnd()->Initialize();

  windowsManager.MainWnd()->SetParams(3, 10, 100, 100); // (num button, margins between buttons in pixels, size x, size y)
  windowsManager.MainWnd()->AddMenuButton(F("Recipe"), win_recipe, &recipe60x60);
  windowsManager.MainWnd()->AddMenuButton(F("Brew"), brew_win, &brew60x60);
  windowsManager.MainWnd()->AddMenuButton(F("Settings"), win_settings, &settings60x60);

  // SensorManager signature
  // SensorManager(ISensor *sensor,
  //               float low_application_limit,
  //               float high_application_limit,
  //               unsigned long pause_length_ms,
  //               bool withBuffer=true, 
  //               const __FlashStringHelper* applicationName=NULL, 
  //               SensorCalibrator *sensorCalibrator=NULL)

  // System temperature variables
  DS18B20Sensor *internal_temp = new DS18B20Sensor(INTERNAL_TEMP,1);
  SensorManager *internal_temp_manager = new SensorManager(internal_temp,-10,110,1000*10, false, F("INTERNAL"));
  sensors.Add(internal_temp_manager);

  internal_temp_manager->RegisterHasDataEventReceiver(windowsManager.MainWnd());
  internal_temp_manager->RegisterMeasuredEventReceiver(windowsManager.MainWnd());

  // Mash temperature variables
  DS18B20Sensor *mash_up_temp = new DS18B20Sensor(MASH_DS_PIN_UP,1);
  DS18B20Sensor *mash_down_temp = new DS18B20Sensor(MASH_DS_PIN_DOWN,1);
    
  SensorManager *internal_temp_manager_up  = new SensorManager(mash_up_temp,-10,110,1000*10, false, F("UP"));
  SensorManager *internal_temp_manager_down = new SensorManager(mash_down_temp,-10,110,1000*10, false, F("DOWN"));
  sensors.Add(internal_temp_manager_up);
  sensors.Add(internal_temp_manager_down);

  internal_temp_manager_up->RegisterHasDataEventReceiver(mash);
  internal_temp_manager_up->RegisterMeasuredEventReceiver(mash);

  internal_temp_manager_down->RegisterHasDataEventReceiver(mash);
  internal_temp_manager_down->RegisterMeasuredEventReceiver(mash);

  DS18B20Sensor *sparge_temp = new DS18B20Sensor(SPARGE_DS_PIN,1);
  SensorManager *spargel_temp_manager = new SensorManager(sparge_temp,-10,110,1000*10, false, F("SPARGE"));
  sensors.Add(spargel_temp_manager);

  spargel_temp_manager->RegisterHasDataEventReceiver(sparge);
  spargel_temp_manager->RegisterMeasuredEventReceiver(sparge);
 
  // In order to avoid pause in the touch interactions, windows manager is defined as critical process
  //measurementNode.SetCriticalProcess(&windowsManager);

  //CONTROLLER SETUP
  mash->InitializeMashController(mashSteps, sizeof(mashSteps)/sizeof(mashStep), mash_water_weight, mash_malts_weight);

  // RELEs
  pinMode(SPARGE_FIRE_PIN, OUTPUT);
  pinMode(MASH_FIRE_PIN, OUTPUT);
  pinMode(SSR_1, OUTPUT);
  pinMode(SSR_2, OUTPUT);

  mash->FireOff();   // Turn off mash fire
  sparge->FireOff(); // Turn off sparge fire
  digitalWrite(SSR_1, HIGH);
  digitalWrite(SSR_2, HIGH);

	AHelper::LogFreeRam();
	delay(1000); 
	out<<F("End setup")<<endln;
}

unsigned long long t = millis();

void loop()
{
  measurementNode.Measure(); // Get data from sensors
	windowsManager.loop(); // Give window manager an opportunity to update display

  if(mash->IsMash()){
     mash->CheckTemperatures(); // Commentare per bollitura
     mash->SetFire();  // Commentare per bollitura
     mash->HandleStep(); // Commentare per bollitura
     mash->UpdateScreenStepData();
  }

   if(sparge->IsSparge()){ 
    sparge->SetTemperatures(); 
    sparge->SetFire(); 
   } 

  if(millis() - t > 5000){
  
//  String a = "prova.txt";
//     out << "a:" << int(&a) << "\n";
//  String b;
//       out << "b_prim:" << int(&b) << "\n";
//  b = f();
//     out << "b:" << int(&b) << "\n";
//  out << "ac: " << a << "\n";
//  out << "bc: " << b << "\n";
//
//  out << "up: " << mash->mash_up_temp_str_->GetText() << "\n";
//  out << "up_string: " << String(mash->buf_up) << "\n";
//  out << "down: " << mash->mash_down_temp_str_->GetText() << "\n";
//  out << "down_string: " << String(mash->buf_down) << "\n";
//
//  out << "avg: " << mash->mash_avg_temp_str_->GetText() << "\n";
//  out << "avg_string: " << String(mash->buf_avg) << "\n";
//
//  out << "fire: " << mash->flames_img_->GetText() << "\n";
//  out << "fire_string: " << String(mash->buf_flames) << "\n";
   t = millis();
  AHelper::LogFreeRam();

  }

  //windowsManager.MainWnd()->UpdateSystemTemp(150.00);
  
}

// Returns the temperature from one DS18S20 in DEG Celsius
float getTemp(OneWire ds){

  byte data[12];
  byte addr[8];

  if ( !ds.search(addr)) {
    // No more sensors on chain, reset search
    ds.reset_search();
    return -1000;
  }

  if ( OneWire::crc8( addr, 7) != addr[7]) {
    //DebugSerialPrintln("Sensor getTemp says: CRC is not valid!");
    return -1000;
  }

  if ( addr[0] != 0x10 && addr[0] != 0x28) {
    //DebugSerialPrintln("Sensor getTemp says:; Device is not recognized");
    return -1000;
  }

  ds.reset();
  ds.select(addr);
  ds.write(0x44,1); // Start conversion, with parasite power on at the end

  byte present = ds.reset();
  ds.select(addr);
  ds.write(0xBE); // Read Scratchpad

  for (int i = 0; i < 9; i++) { // We need 9 bytes
    data[i] = ds.read();
  }

  ds.reset_search();

  byte MSB = data[1];
  byte LSB = data[0];

  float tempRead = ((MSB << 8) | LSB); // Using two's compliment
  float TemperatureSum = tempRead / 16;

  return TemperatureSum;
}

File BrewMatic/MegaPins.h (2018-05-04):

#ifndef MEGA_PINS
#define MEGA_PINS

//************************************************************
// BUTTONs
//************************************************************

//#define BTN_ALARM ??
#define BTN_1 A10
#define BTN_2 A11
#define BTN_3 A12
#define BTN_4 A13
#define BTN_5 A14
#define BTN_6 A15

//************************************************************
// LCDs
//************************************************************

// MASH LCD bright pin
//#define MASH_PWM_LED_PIN 2 // must be PWM
// MASH LCD other pins
#define MASH_PIN_LCD_RS 32//33//39
#define MASH_PIN_LCD_EN 22//35//41
#define MASH_PIN_LCD_D4 24//37//43
#define MASH_PIN_LCD_D5 26//39//45
#define MASH_PIN_LCD_D6 28//41//47
#define MASH_PIN_LCD_D7 30//43//49

// BOIL LCD bright pin
//#define BOIL_PWM_LED_PIN 3 // must be PWM
// BOIL LCD other pins
#define BOIL_PIN_LCD_RS 34//30//39
#define BOIL_PIN_LCD_EN 36//28//41
#define BOIL_PIN_LCD_D4 38//45//43
#define BOIL_PIN_LCD_D5 44//47//45
#define BOIL_PIN_LCD_D6 42//49//47
#define BOIL_PIN_LCD_D7 40//51//49

// SPARGE LCD bright pin
//#define SPARGE_PWM_LED_PIN 4 // must be PWM
// SPARGE other pins
#define SPARGE_PIN_LCD_RS 23//39
#define SPARGE_PIN_LCD_EN 25//41
#define SPARGE_PIN_LCD_D4 27//43
#define SPARGE_PIN_LCD_D5 29//45
#define SPARGE_PIN_LCD_D6 31//47
#define SPARGE_PIN_LCD_D7 33//49

// MESSAGE LCD bright pin
//#define MSG_PWM_LED_PIN 5 // must be PWM
// MESSAGE LCD other pins
#define MSG_PIN_LCD_RS 41
#define MSG_PIN_LCD_EN 37
#define MSG_PIN_LCD_D4 43
#define MSG_PIN_LCD_D5 45
#define MSG_PIN_LCD_D6 47
#define MSG_PIN_LCD_D7 49


//************************************************************
// LEDs - RELEs
//************************************************************

#define MASH_FIRE_PIN A0    // Pin of mash electrovalve's rele --> IN1 on rele board
#define MASH_LED_PIN A6     // Led that say when the mash's fire is ON

#define SPARGE_FIRE_PIN A1 // Pin of sparge electrovalve's rele --> IN2 on rele board
#define SPARGE_LED_PIN A7   // Led that say when the sparge's fire is ON

#define REPLACEMENT_RELE A2 // --> IN3 on rele board
#define REPLACEMENT_RELE A3 // --> IN4 on rele board

#define MSG_LED_PIN A8   // Led for messages

//************************************************************
// BUZZER
//************************************************************

#define BUZZER A9

//************************************************************
// TEMPERATURE SENSORs - NEW PLANT UPDATED
//************************************************************

#define MASH_DS_PIN_UP A7 // Most left XLS input on the case (left SIG1 PIN on the MOBO)
#define MASH_DS_PIN_DOWN A6 // Second left XLS input on the case (left SIG2 PIN on the MOBO)

#define MASH_DS_REPLACEMENT_PIN A9 // Used to get temperature insed the case and to calculate "mash in" correct temperature (TODO UPDATE THIS FUNCTIONALITY)

#define SPARGE_DS_PIN 4 // Third left XLS input on the case (right SIG1 PIN on the MOBO)
#define SPARGE_DS_REPLACEMENT_PIN 5 // Most right XLS input on the case (right SIG2 PIN on the MOBO)

//************************************************************
// ROTATIVE ENCODER - NEW PLANT UPDATED
//************************************************************

#define RE_CLK 3
#define RE_DT 2
#define RE_SW 18

#endif // MEGA_PINS

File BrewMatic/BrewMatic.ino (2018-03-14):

//************************************************************
// INCLUDED LIBRARIES
//************************************************************

#include <SPI.h>
#include <string.h>

// Included for hadle Arduino WatchDog
#include <avr/wdt.h>
#include <avr/interrupt.h>

// Included to check free memory
#include <MemoryFree.h>

// Included to handle display
#include <LiquidCrystal.h>

// Included to handle EEPROM
#include <EEPROMex.h>

// Included to read temperature
#include <OneWire.h>

// It is really necessary??
#include "Arduino.h"

// My libs: 
#include "utilities.h"
#include "Boil.h" // To handle boil process
#include "Mash.h" // To handle mash process
#include "sparge.h" // To handle sparge process
#include "Buttons.h"  // To handle buttons
#include "MegaPins.h" // To handle pin numbers/connections
#include "temp.h" // To handle temperature sensor
#include "buzzer.h" // To handle buzzer

//************************************************************
// LCD/SETUP/STATE GLOBAL VARIABLES
//************************************************************
  
// Initialize the LCD display library with the numbers of the interface pins
LiquidCrystal lcdSparge( SPARGE_PIN_LCD_RS, SPARGE_PIN_LCD_EN, SPARGE_PIN_LCD_D4, SPARGE_PIN_LCD_D5, SPARGE_PIN_LCD_D6, SPARGE_PIN_LCD_D7 );
LiquidCrystal lcdMash( MASH_PIN_LCD_RS, MASH_PIN_LCD_EN, MASH_PIN_LCD_D4, MASH_PIN_LCD_D5, MASH_PIN_LCD_D6, MASH_PIN_LCD_D7 );

LiquidCrystal lcdBoil( BOIL_PIN_LCD_RS, BOIL_PIN_LCD_EN, BOIL_PIN_LCD_D4, BOIL_PIN_LCD_D5, BOIL_PIN_LCD_D6, BOIL_PIN_LCD_D7 );
LiquidCrystal lcdMsg( MSG_PIN_LCD_RS, MSG_PIN_LCD_EN, MSG_PIN_LCD_D4, MSG_PIN_LCD_D5, MSG_PIN_LCD_D6, MSG_PIN_LCD_D7 );



//************************************************************
// SENSOR GLOBAL VARIABLES
//************************************************************

OneWire mashUpDs(MASH_DS_PIN_UP);
OneWire mashDownDs(MASH_DS_PIN_DOWN);
OneWire mashEnvDs(MASH_DS_REPLACEMENT_PIN);

OneWire spargeDs(SPARGE_DS_PIN);
OneWire boilDs(BOIL_DS_PIN);

Buttons btns;
APlayer player(BUZZER);
Buzzer bzr(&btns, &player);

//************************************************************
// RECIPE VARIABLES
//************************************************************

#include "Recipe.h"

MashClass mash(mashSteps, sizeof(mashSteps)/sizeof(mashStep), mash_water_weight, mash_malts_weight, &mashUpDs, &mashDownDs, &mashEnvDs, &lcdMash, &LcdDisplayConfigParams, &btns, &bzr);
BoilClass boil(boilSteps, sizeof(boilSteps)/sizeof(boilStep), totalBoilMinutes, &boilDs, &lcdBoil, &LcdDisplayConfigParams, &btns, &bzr); 
SpargeClass sparge(&spargeDs, &lcdSparge);


//************************************************************
// PLANT VARIABLES
//************************************************************

#include "PlantParams.h"

/*
  SD card read/write

 This example shows how to read and write data to and from an SD card file
 The circuit:
 * SD card attached to SPI bus as follows:
 ** MOSI - pin 11
 ** MISO - pin 12
 ** CLK - pin 13
 ** CS - pin 4 (for MKRZero SD: SDCARD_SS_PIN)

*/

#include <SD.h>

void setup(void)
{
  // Setup serial port
#ifdef DEBUG
  Serial.begin(9600);
  while (!Serial) {
    ; // wait for serial port to connect. Needed for native USB port only
  } 
#endif

  // LEDs
  pinMode(MSG_LED_PIN, OUTPUT);
  pinMode(SPARGE_LED_PIN, OUTPUT);
  pinMode(MASH_LED_PIN, OUTPUT);

 // RELEs
  pinMode(SPARGE_FIRE_PIN, OUTPUT);
  pinMode(MASH_FIRE_PIN, OUTPUT);
  
  mash.FireOff();   // Turn off mash fire
  sparge.FireOff(); // Turn off sparge fire 

  sparge.FireOn(); // Per accendere fornello di sparge se serve un fuoco durante il boil

  // Initialize SD card
  DebugSerialPrintln(F("Initializing SD card..."));
  if (!SD.begin(53)) {
      DebugSerialPrintln(F("initialization failed!"));
  }else{
      is_sd_ok = true;
      DebugSerialPrintln(F("initialization complete!"));
  }

  // Reading backup from files if necessary
  if(!btns.IsPressed(RESET_BTN, 5000)){
      // Restore previous state reading it from file
      mash.Deserialize(); 
      boil.Deserialize();
      UtilityDeserialize();
      
      LcdDisplayConfigParams();
  }

  // Setup LCDs
  lcdMash.begin(20, 4);
  lcdMash.createChar(topRightArrow, newTopRightArrow);
  
  lcdBoil.begin(20, 4);
  lcdSparge.begin(16, 2); 
  lcdMsg.begin(16, 2);

  // Display LCD's first values 
  mash.DisplayLcd();
  sparge.DisplayLcd();
  boil.DisplayLcd();
  LcdDisplayConfigParams();
} // setup

void loop()
{ 
  // Begin SD if necessary
  if (!is_sd_ok){
      DebugSerialPrintln(F("Initializing SD card..."));
      if (!SD.begin(53)) {
          DebugSerialPrintln(F("initialization failed!"));
      }else{
          is_sd_ok = true;
          DebugSerialPrintln(F("initialization complete!"));
      }
  }

  // Reset arduino if requested
  if(btns.IsPressed(RESTART_BTN, 1000)){
       Backup(true);
       wdt_enable(WDTO_15MS);
       while(1){}; // Rebooting
  }
  
  mash.SetTemperatures(); 
  mash.DisplayLcd();
  
  sparge.SetTemperatures();
  sparge.DisplayLcd();
  
  boil.SetTemperatures();
  boil.DisplayLcd();   

  LcdDisplayConfigParams();

  if(sparge.IsSparge()){ sparge.SetFire(); } 

  if(mash.IsMash()){
    
     mash.CheckTemperatures();   
     mash.SetFire();  
     
     mash.HandleStep();   
  } 

  if(mash.IsMashSpargeTransition()){
      if(mash.TestIfSpargeDone()){
          boil.SetIsToTestBoil();
      }
  }
  
  if(boil.IsToTestBoil()){
      //mash.FireOn(); // Decommenta per fare boil su fugone intermedio
      boil.TestIfStartBoil();
  }

  if(boil.IsBoiling()){
      boil.TestIfHoppedHop();
  }

  Backup(false); // Backup data on SD 
  delay(1000);
}// loop

//************************************************************
// LCD FUNCTIONS: begin
//************************************************************
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

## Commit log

2018-02-26 Add datasheets and schematics for touchscreen modules
2018-03-01 Add hardware list
    [Elenco Oggetti.xlsx]
2018-03-14 Update Objects List.xlsx
    [Elenco Oggetti.xlsx]
2018-03-14 Introduce useful files
    [Objects List.xlsx, SchemaPins.xlsx, XLSdoppio.fzz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]
2018-03-15 Update object list
    [Objects List.xlsx]
2018-03-26 Small improvements
    [Arduino-Board Bridge 1.fzz, Arduino-Board Bridge 2.fzz, Motherboard.fzz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]
2018-03-30 Update Objects List.xlsx + Add SD with software SPI and LCD shield example code
    [Objects List.xlsx]
2018-04-07 Update PCBs
    [Motherboard.fzz, XLS Doppio.fzz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]
2018-04-12 Update circuits
    [Arduino-Board Bridge 2.fzz, Bridges_XLS.fzz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]
2018-04-18 Update PCBs and Case files
    [Arduino-Board Bridge 1.fzz, Arduino-Board Bridge 2.fzz, Bridges_XLS.fzz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]
2018-04-22 Add example sketch to get temperatures
2018-05-04 Update libraries and PCB files
    [Motherboard.fzz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]
2018-05-04 Add OneWire library and update some values in MegaPins.h header file
    [Motherboard.fzz]
2018-08-19 Finalize home window with buttons and system temperature
    [Character Code Generator.xlsx]
2019-03-19 Add model and GCode per single XLS Temp Sensor
    [XLS Single.fzz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]
